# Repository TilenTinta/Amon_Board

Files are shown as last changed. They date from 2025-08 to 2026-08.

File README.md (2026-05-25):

# Amon Board — Flight Controller & Firmware

**Project Status:** In Progress

# Description:
Flight controller hardware and firmware used in the Amon Lander project. Two hardware lines are maintained:
- **Board v1 (ESP32 WROOM-32)** — never released (critical error).
- **Board v2 (STM32F405)** — the current, working design.
- **Board v3 (STM32H743VIT6)** — in development.
- **Board v4 (STM32xxx (Zephyr) + Raspberry Pi CM4)** — the next-gen design with a new MCU running Zephyr RTOS and a companion **Raspberry Pi Compute Module 4 (CM4)**.

> Part of the Amon Lander project:
>
> - **Amon Lander** — overall vehicle, frame, test/control SW, and data  
>   https://github.com/TilenTinta/Amon_Lander  
> - **Amon Link** — PC - drone communications (PCB + firmware)  
>   https://github.com/TilenTinta/Amon_Link  
> - **Amon Ground Control** — desktop GCS for telemetry & control  
>   https://github.com/TilenTinta/Amon_GroundControl_Software

---

## Table of Contents

- [Overview](#overview)
- [Hardware Versions](#hardware-versions)
  - [Board v2 — STM32F405](#board-v1--stm32f405)
  - [Board v3 — STM32H743](#board-v1--stm32h743)
  - [Board v4 — Zephyr + CM4](#board-v2--zephyr--cm4)
- [Version Matrix](#version-matrix)
- [Repository Structure](#repository-structure)
- [Getting Started](#getting-started)
  - [Build & Flash: Board v2 & v3](#build--flash-board-v1)
  - [Build & Flash: Board v4 (Zephyr)](#build--flash-board-v2-zephyr)
  - [First Boot: CM4 Companion](#first-boot-cm4-companion)
- [Calibration & Testing](#calibration--testing)
- [Roadmap](#roadmap)
- [Status & Disclaimer](#status--disclaimer)
- [License](#license)
- [Acknowledgments](#acknowledgments)

---

## Overview

This board is a custom flight controller for **Amon Lander**. The **v2** generation uses an **STM32F405RGT6 (LQFP-64)** and a hand-written firmware stack (drivers from scratch, for learning and control). Because of the flight algorithm planned to be used in this project, the decision was made to modify the current **v2** PCB with a new MCU. This is the **STM32H743VIT6 (LQFP-100)** and to fix some issues and add features that were missing or incorrect in the previous version. A **v3** generation is being designed around a **Zephyr-supported MCU** for real-time control, that will be paired with a **Raspberry Pi CM4** for high-level tasks (GCS link, logging, navigation stack, future CV/ML, etc.) in **v4**.

Everything was built from the ground up — **electronics, firmware, and software**. Most tools used are **free** and widely available to makers. Expect a learning-first approach over simplicity: some solutions could be easier, but the point is to **learn and explore**.

---

## Hardware Versions

### Board v1 — ESP32 WROOM-32

**Highlights**

- **MCU:** ESP32 WROOM-32 module
- **Power & Protection**
  - Dual vertical **XT60** inputs (PCB PWR and EDF voltage)
  - **Reverse-polarity diode**
  - Max input tested: **12 V**
  - Two **LDO regulators**: 3.3V (MCU/sensors) & 5V/5A (servos)
- **Sensors**
  - **MPU6050** (IMU)
  - **BME280** (temp/pressure/humidity)
  - TOF connector for **VL53L1X**
- **Navigation & Comms**
  - **GPS** connector (GY-NEO6MV2)
  - **single NRF24L01+ PA/LNA** (RX–TX) module
  - **ESP32 WiFi** can be used for communication
- **I/O**
  - **PWM:** 4× servos + 1× EDF
  - Expansion: **SPI** & **I²C** headers
  - **USB** with surge protection (over CH340C)
  - **4-pin JTAG** header
  - **RGB status LED**
  - **Buzzer**
- **Storage:** **microSD** slot
- **PCB:** 4-layer

**Firmware (v1)**
- **Status:** Never really worked (ESP32 was eliminated from the project)

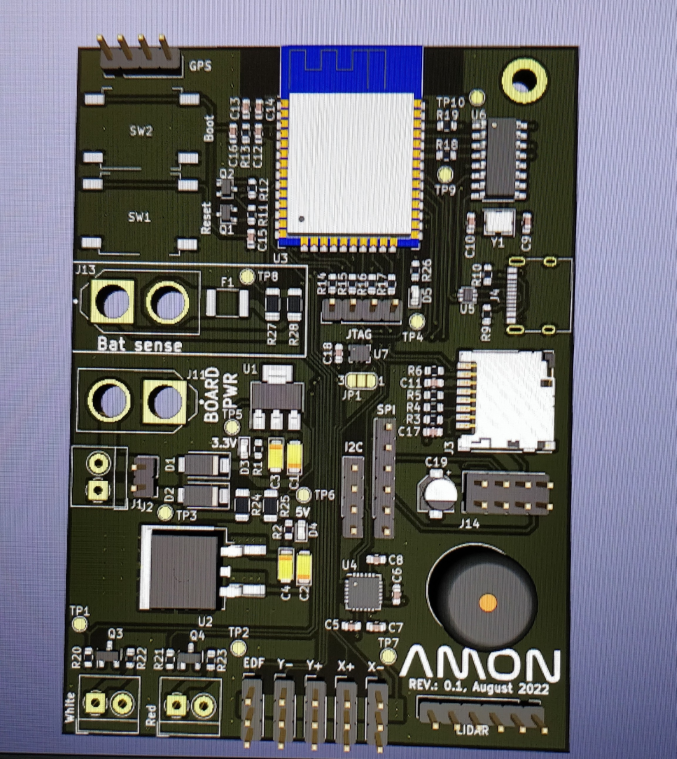
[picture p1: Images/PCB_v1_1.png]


### Board v2 — STM32F405

**Highlights**

- **MCU:** STM32F405RGT6 (LQFP-64) - Cortex M4, 168MHz, 196kB RAM, 1MB Flash
- **Power & Protection**
  - Dual vertical **XT60** inputs (PCB PWR and EDF voltage)
  - **Reverse-polarity diode**
  - Max input tested: **12 V**
  - Two **buck regulators**: 3.3 V (MCU/sensors) & 5 V (servos), ~5 A each
- **Switching/Startup:** Power-on by battery insertion or external switch on a terminal
- **Grounding:** Grounded mounting holes
- **Sensors**
  - **MPU6050** (IMU)
  - **BME280** (temp/pressure/humidity)
  - **HMC5883L** (compass) *added later
  - TOF connector for **VL53L1X**
- **Navigation & Comms**
  - **GPS** connector (GY-NEO6MV2; also reused for calibration)
  - **2× NRF24L01+ PA/LNA** (RX–TX)
- **I/O**
  - **PWM:** 4× servos + 1× EDF (configurable)
  - Expansion: **SPI** & **I²C** headers
  - **USB OTG** with surge protection
  - **10-pin JTAG** header
  - **RGB status LED**
- **Storage:** External flash (telemetry) + **microSD** slot
- **PCB:** 4-layer, working but slated for a future revision/refresh

**Firmware (v2)**

- **Approach:** Minimal dependencies; **drivers from scratch** (for learning)  
- **Status:** Runs and evolves; some drivers may still have rough edges  
- **Focus:** Bring-up, sensor fusion, basic control loops, telemetry logging and transmition...

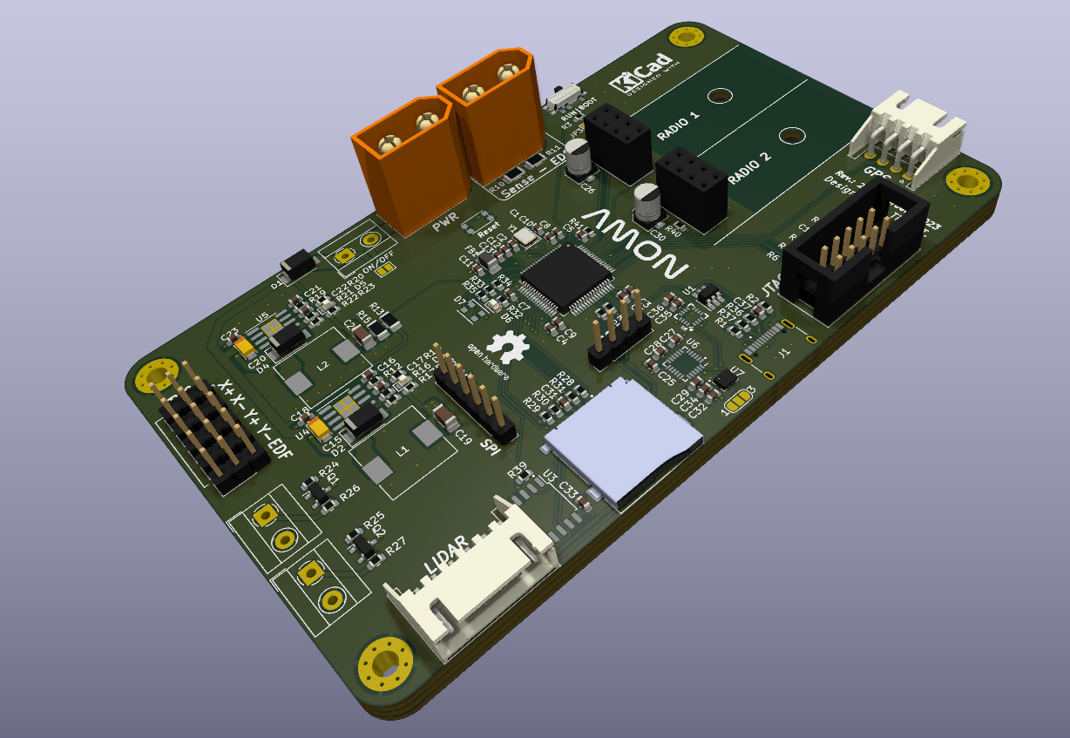
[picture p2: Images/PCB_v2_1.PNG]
PCBv2_1
> 

### Board v3 — STM32H743

**Highlights**

- **MCU:** STM32H743VIT66 (LQFP-100) - Cortex M7, 480MHz, 1MB RAM, 2MB Flash
- **Power & Protection**
  - Dual horizontal **XT60** inputs (PCB PWR and EDF voltage)
  - **Reverse-polarity diode**
  - Max input tested: **12 V**
  - Three **buck regulators**: 3.3 V (MCU/sensors) & 5 V (ESC and placeholder) & 7.2 V (servos), ~5 A each + more stable voltage
- **Switching/Startup:** Power-on sequence 3.3V -> 5V -> 7.2V (monitoring of regulators output voltages and enable/disable function)
- **Grounding:** Grounded mounting holes
- **Sensors**
  - **MPU6050** (IMU)
  - **BME280** (temp/pressure/humidity)
  - **HMC5883L** (compass)
  - Connector for TOF - **VL53L1X**
  - Connector for optical flow - **PMW3901**
- **Navigation & Comms**
  - Connector for GPS module -**GY-NEO6MV2**
  - **2× NRF24L01+ PA/LNA** (RX–TX) now on PCB - eliminated use of modules
  - **USB** over serial chip (CH340G) - eliminated use of USB OTG
- **I/O**
  - **PWM:** 4× servos + 1× EDF
  - Expansion: **SPI** & **I²C** headers
  - **10-pin JTAG** header (Olimex HAB-VCR-010-LF)
  - **RGB status LED**
  - **Single RED status LED**
  - Three connector low **LED modules** and additional AUX connector for future use
- **Storage:** External flash (telemetry) + **microSD** slot
- **PCB:** 4-layer

**Firmware (v3)**

- **Base:** Firmware is fully based on **Firmware v2**
- **Approach:** Minimal dependencies; **drivers from scratch** (for learning)  
- **Status:** Runs and evolves; some drivers may still have rough edges  
- **Focus:** sensor fusion, advance control algorithms, telemetry logging and transmition...

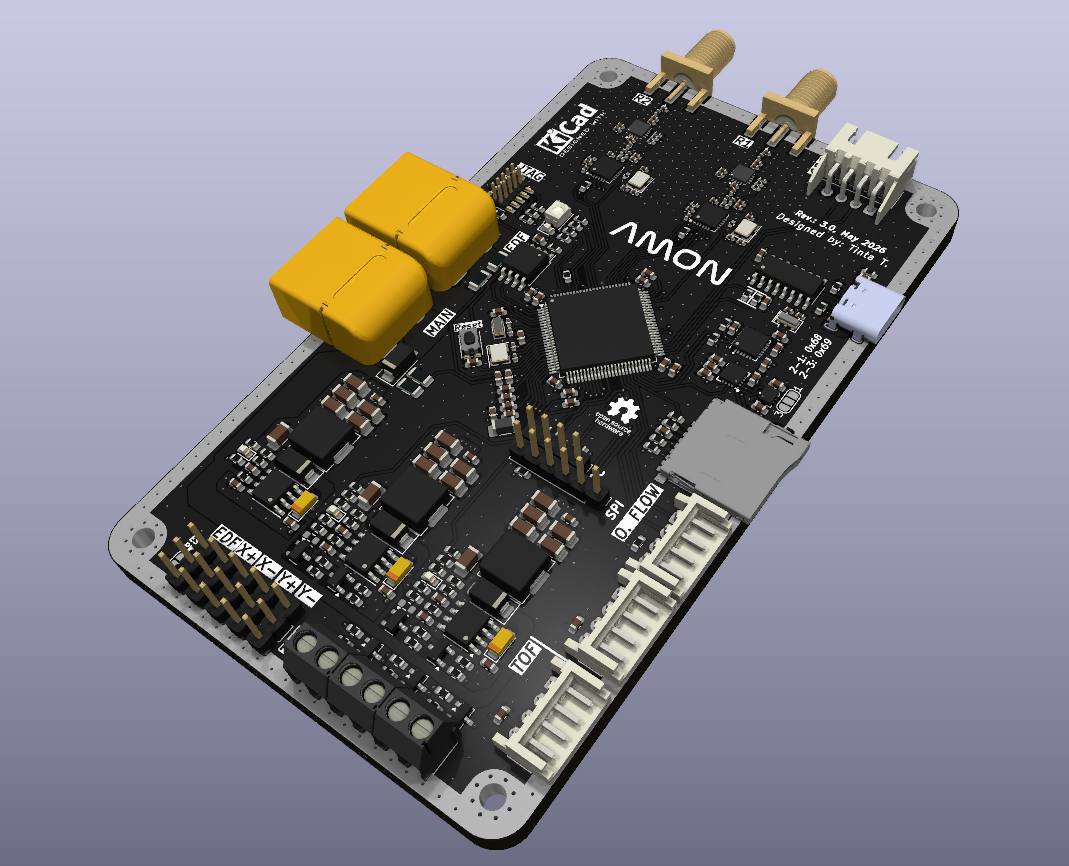
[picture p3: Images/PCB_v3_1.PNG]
PCBv3_1
> 

---

### Board v4 — Zephyr + CM4

**Architecture (planned / in development)**

- **Real-time MCU (Zephyr)**  
  - New MCU (TBD; Zephyr-supported) handles **Real-time**:
    - Sensor acquisition & fusion
    - Control loops (attitude/rate, TVC/actuators, EDF control)
    - Safety interlocks & failsafes
    - Deterministic logging (to QSPI flash / SD)
  - **Zephyr RTOS** app with:
    - Devicetree-based pin/peripheral config
    - Workqueues/threads for IMU, baro, magnetometer, TOF, PWM
    - Shell/CLI over UART/USB for diagnostics
    - Config storage (NVS) and firmware update hooks

- **Companion Computer — Raspberry Pi CM4**  
  - Runs services for:
    - Ground link, mission control, high-rate logging
    - Navigation stack expansion (mapping, state estimation helpers)
    - Future CV/ML applications (optional)
  - **Link to MCU:** UART (primary) + SPI/CAN (optional)  
  - **Services:** Telemetry bridge (to Amon Link), data recorder, configuration UI server
  - **OS:** Raspberry Pi OS Lite (or other lightweight Linux)

**Electrical**
- Robust power tree with multiple separated rails for servos/EDF vs logic
- MCU - CM4 isolation where needed (level shifting/ESD)
- On-board mass storage for logs (eMMC on CM4 + SD/QSPI on MCU)
- External debug: SWD/JTAG for MCU; USB-C or Ethernet for CM4

**Firmware (v4)**

- **Zephyr** application (modules: sensors, control, comms, storage)
- **IPC format:** CBOR/Protobuf frame over UART (CRC-guarded)
- **Bootloaders & Updates:** MCU bootloader (serial/DFU), CM4 apt-based or containerized deployment
- **Testing:** HIL hooks; replay logs for control tuning

---

## Version Matrix

## Version Matrix

| Capability | Board v1 — ESP32 | Board v2 — STM32F405 | Board v3 — STM32H743 | Board v4 — Zephyr + CM4 |
|---|---|---|---|---|
| MCU | ESP32 WROOM-32 | STM32F405RGT6 | STM32H743VIT6 | **TBD (Zephyr-supported)** |
| RTOS | None | None (bare-metal) | None (bare-metal) | **Zephyr RTOS** |
| Companion Computer | — | — | — | **Raspberry Pi CM4** |
| Sensors | MPU6050, BME280, VL53L1X | MPU6050, BME280, HMC5883L, VL53L1X | MPU6050, BME280, HMC5883L, VL53L1X | Same class; final selection TBD |
| Radio | 1× NRF24L01+ PA/LNA | 2× NRF24L01+ PA/LNA | 2× NRF24L01+ PA/LNA | TBD (NRF / other via MCU or CM4) |
| Navigation | GPS (GY-NEO6MV2) | GPS (GY-NEO6MV2) | GPS (GY-NEO6MV2) | GPS via MCU or CM4 module |
| Storage | microSD | Flash + microSD | Flash + microSD | CM4 eMMC + MCU flash/SD  |
| USB | USB (CH340C) | USB OTG | USB OTG + CH340G | USB (MCU + CM4) |
| Programming / Debug | 4-pin JTAG | 10-pin JTAG | 10-pin JTAG | SWD/JTAG (MCU) + SSH/USB/Ethernet (CM4) |
| PWM Outputs | 4× servos + 1× EDF | 4× servos + 1× EDF | 4× servos + 1× EDF | Same (handled by MCU) |
| Expansion | SPI, I²C | SPI, I²C | SPI, I²C | SPI, I²C, UART, CAN (planned) |
| Power | XT60, LDO (3.3V + 5V/5A) | XT60, buck (3.3V + 5V/5A + 7.2V) | XT60, improved buck (3.3V + 5V/5A) | Segregated rails, higher headroom (TBD) |
| PCB | 4-layer | 4-layer | 4-layer | TBD |
| Firmware Status | Not working | Working, evolving | In development | In development |
| Firmware Approach | — | Bare-metal, custom drivers | Based on v2, improved | Zephyr modules + Linux services |
| Firmware Updates | USB | JTAG/SWD/DFU | JTAG/SWD/DFU | MCU bootloader + CM4 (apt/container) |

---

## Getting Started

### Build & Flash: Board v1

1. **Clone**
   ```bash
   git clone https://github.com/<your-org-or-user>/Amon_Board.git
   cd Amon_Board/firmware/Amon_board_firmware-MCU
   ```
2. **Toolchain**
   - Install `arm-none-eabi-gcc` and your preferred STM32 flashing tool.
3. **Configure - can be automatic**
   - Target: **STM32F405RG**; enable FPU; set clock tree; verify linker script.
4. **Build**
   ```bash
   make
   ```
   or use your IDE’s Build action.
5. **Flash**
   - Via **JTAG/SWD** (10-pin header) using your probe (ST-Link, J-Link, etc.).
6. **Verify**
   - Rails at 5 V/3.3 V, sensor presence on I²C/SPI, status RGB LED patterns.

---

### Build & Flash: Board v2 (Zephyr)
Instructions bellow are only "place holder". Detailed instructions will be provided once the development will be started. For flashing and debugging will be used Segger Ozone software.

1. **Prerequisites**
   - Install **Zephyr SDK**, Python, CMake, Ninja.
   - Install **west**: `pip install west`
2. **Get Sources**
   ```bash
   cd Amon_Board/firmware/v2-zephyr
   west init -l .
   west update
   ```
3. **Board Definition**
   - Use the custom board under `boards/amon_v2/` (edit SoC, pins, clocks, and flash layout as needed).
4. **Build**
   ```bash
   west build -b amon_v2 app
   ```
5. **Flash**
   ```bash
   west flash
   ```
6. **Console**
   ```bash
   west espressif monitor   # or 'west zephyr monitor' / minicom, depending on target
   ```
   *(Choose the appropriate monitor command for your MCU/OS.)*

---

### First Boot: CM4 Companion

1. **Flash OS**
   - Install **Raspberry Pi OS Lite** to CM4’s eMMC or carrier-board storage.
2. **Enable Interfaces**
   - `sudo raspi-config` → enable UART, I2C, SPI as needed.
3. **Install Services**
   ```bash
   sudo apt update
   sudo apt install python3-pip git
   git clone https://github.com/<your-org-or-user>/amon-cm4-services.git
   cd amon-cm4-services && ./install.sh
   ```
   - Starts a telemetry bridge (serial↔TCP/gRPC), data logger, and config UI.
4. **Connect to MCU**
   - Wire UART (and optionally SPI/CAN) between CM4 and MCU.
   - Confirm link with a ping/handshake command.
5. **Network Access**
   - SSH into CM4; forward telemetry to **Amon Ground Control** over Wi-Fi/Ethernet.

---

## Calibration & Testing

- **GPS/Calibration Port:** The v2 GPS connector doubles as a calibration interface during bring-up. PCB v3 do this over USB.  
- **Telemetry:** Log to external flash/microSD (v2 & v3) or CM4 eMMC + MCU storage (v4).  
- **LED Status:** On-board RGB LED signals power, init, errors, and link status.  
- **HIL/Replay (v2):** Reproduce flights by streaming recorded sensor frames back into the MCU (for controller tuning).

---

## Roadmap

- **v1**
   - Failed design
- **v2**
  - Incremental driver fixes and documentation cleanup
  - Manufacturing files refresh (Gerbers/BOM/PNP)
- **v3**
   - Modified v2 design with new MCU, connectors, sensors
   - Modified v2 firmware for new MCU (much higher clock: 168 MHz -> 480MHz)
   - Development of flight algorithm and controller + first flights 
- **v4**
  - Finalize MCU choice and Zephyr board port
  - Define IPC schema (CBOR/Proto) & reliability (CRC/seq/ACK)
  - CM4 services (logger, bridge, config UI)
  - Development of new flight algorithm and controllers + flights 

---

## Status & Disclaimer

- **Works, but in progress:** v2 firmware runs; development is active and some drivers may still have rough edges.  
- **New hardware incoming:** v2/v3/v4 will introduce a Zephyr-based MCU and CM4 companion; designs are evolving.

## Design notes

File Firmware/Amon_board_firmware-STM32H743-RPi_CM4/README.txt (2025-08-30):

1) MCU

2) RPi
	- optical flow
	- shared memory
	- multi process (UART, CAM + QOI?, RFTX, RFRX, GPS, Optical flow)

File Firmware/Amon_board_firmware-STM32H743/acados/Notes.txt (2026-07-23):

Run auto copy and modify code from powershell with:
powershell.exe -ExecutionPolicy Bypass -File ".\update_acados_files.ps1"

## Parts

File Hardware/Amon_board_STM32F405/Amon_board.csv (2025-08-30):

Id | Designator | Package | Quantity | Designation
1 | JP2 | SolderJumper-3_P2.0mm_Open_TrianglePad1.0x1.5mm_NumberLabels | 1 | I2C address
2 | H2,H1,H4,H3 | MountingHole_3.2mm_M3_Pad_Via | 4 | MountingHole_Pad
3 | R7,R9,R8,R6 | R_0603_1608Metric | 4 | 100
4 | C14,C21,C16,C13,C10,C5,C34,C9,C7,C32,C8 | C_0603_1608Metric | 11 | 100nF
5 | J4,J5 | AMASS_XT60-M | 2 | XT60-F
6 | J14 | PinHeader_1x04_P2.54mm_Vertical | 1 | Conn_01x04_Male
7 | R25,R24,R26,R27 | R_0603_1608Metric | 4 | 1k
8 | R13,R10 | R_1206_3216Metric | 2 | 100k
9 | R34,R33,R32,R35 | R_0603_1608Metric | 4 | 330
10 | R12,R19 | R_0603_1608Metric | 2 | 100k
11 | L1,L2 | L_10.4x10.4_H4.8 | 2 | 10uH 4A
12 | R22 | R_0603_1608Metric | 1 | 44k
13 | R17 | R_0603_1608Metric | 1 | 26k1
14 | C25,C27,C28 | C_0603_1608Metric | 3 | 0.1uF
15 | D4,D2,D1 | D_SMA | 3 | B120-E3
16 | J7 | TerminalBlock_MetzConnect_Type055_RT01502HDWU_1x02_P5.00mm_Horizontal | 1 | Red leds
17 | U3 | SOIC-8_5.23x5.23mm_P1.27mm | 1 | W25Q128JVS
18 | R1,R2 | R_0603_1608Metric | 2 | 5k1
19 | J9,J6 | PinSocket_2x04_P2.54mm_Vertical | 2 | Conn_02x04_Odd_Even
20 | U7 | Bosch_LGA-8_2x2.5mm_P0.65mm_ClockwisePinNumbering | 1 | BME280
21 | J3 | TerminalBlock_MetzConnect_Type055_RT01502HDWU_1x02_P5.00mm_Horizontal | 1 | Switch_port
22 | R3,R29,R30,R21,R28,R31,R16 | R_0603_1608Metric | 7 | 10k
23 | M4 | PinHeader_1x03_P2.54mm_Vertical | 1 | Servo_Y-
24 | C15,C20 | CP_EIA-3216-10_Kemet-I | 2 | 10uF
25 | J2 | IDC-Header_2x05_P2.54mm_Vertical | 1 | Conn_2x5 pin
26 | R18,R23 | R_0603_1608Metric | 2 | 1k5
27 | J8 | TerminalBlock_MetzConnect_Type055_RT01502HDWU_1x02_P5.00mm_Horizontal | 1 | White leds
28 | J11 | PinHeader_1x03_P2.54mm_Vertical | 1 | Conn_01x03_Male
29 | J1 | USB_C_Receptacle_XKB_U262-16XN-4BVC11 | 1 | USB2.0_C_Rev
30 | C12,C33,C11 | C_0603_1608Metric | 3 | 1uF
31 | JP3 | SolderJumper-2_P1.3mm_Open_TrianglePad1.0x1.5mm | 1 | SolderJumper_2_Open
32 | C2,C1 | C_0603_1608Metric | 2 | 14pF
33 | U1 | SOT-23-6_Handsoldering | 1 | USBLC6-2P6
34 | R4,R5 | R_0603_1608Metric | 2 | 4k7
35 | J12 | JST_XH_S6B-XH-A-1_1x06_P2.50mm_Horizontal | 1 | Conn_01x06_Male
36 | M2 | PinHeader_1x03_P2.54mm_Vertical | 1 | Servo_X-
37 | C24,C19 | C_0603_1608Metric | 2 | 22uF
38 | J10 | AMPHENOL_GTFP08131Y2HR | 1 | GTFP08131Y2HR
39 | SW2 | SW_Push_1P1T_NO_CK_KMR2 | 1 | SW_SPST
40 | C3 | C_0603_1608Metric | 1 | 4.7uF
41 | U5,U4 | SOIC-8-1EP_3.9x4.9mm_P1.27mm_EP2.62x3.51mm | 2 | MP2303ADN
42 | FB1 | L_1206_3216Metric_Pad1.22x1.90mm_HandSolder | 1 | 100R 100MHz
43 | C31 | C_0603_1608Metric | 1 | 10uF
44 | C22,C17 | C_0603_1608Metric | 2 | 3.9nF
45 | R20,R14 | R_0603_1608Metric | 2 | 6k8
46 | SW1 | SW_SPDT_PCM12 | 1 | SW_DPDT
47 | J13 | JST_XH_S4B-XH-A_1x04_P2.50mm_Horizontal | 1 | Conn_01x04_Male
48 | Y1 | Crystal_SMD_3225-4Pin_3.2x2.5mm | 1 | 25MHz
49 | C30,C26 | CP_Elec_4x5.4 | 2 | 10uF
50 | D3,D5 | LED_0603_1608Metric | 2 | Red
51 | C18,C23 | C_0603_1608Metric | 2 | 10nF
52 | R15,R11 | R_1206_3216Metric | 2 | 10k
53 | D7 | LED_Cree-PLCC4_3.2x2.8mm_CCW | 1 | LED_RGBA
54 | Q1,Q2 | SOT-23 | 2 | BC817
55 | C4,C6 | C_0603_1608Metric | 2 | 2.2uF
56 | U2 | LQFP-64_10x10mm_P0.5mm | 1 | STM32F405RGT6-LQFP64
57 | U6 | InvenSense_QFN-24_4x4mm_P0.5mm | 1 | MPU-6050
58 | M1 | PinHeader_1x03_P2.54mm_Vertical | 1 | Servo_X+
59 | JP1 | SolderJumper-2_P1.3mm_Open_Pad1.0x1.5mm | 1 | SolderJumper_2_Open
60 | M3 | PinHeader_1x03_P2.54mm_Vertical | 1 | Servo_Y+
61 | J15 | PinHeader_1x06_P2.54mm_Vertical | 1 | Conn_01x06_Male
62 | C29 | C_0603_1608Metric | 1 | 2.2nF
63 | D6 | LED_0603_1608Metric | 1 | RED
64 | H6,H5 | MountingHole_3.2mm_M3 | 2 | MountingHole

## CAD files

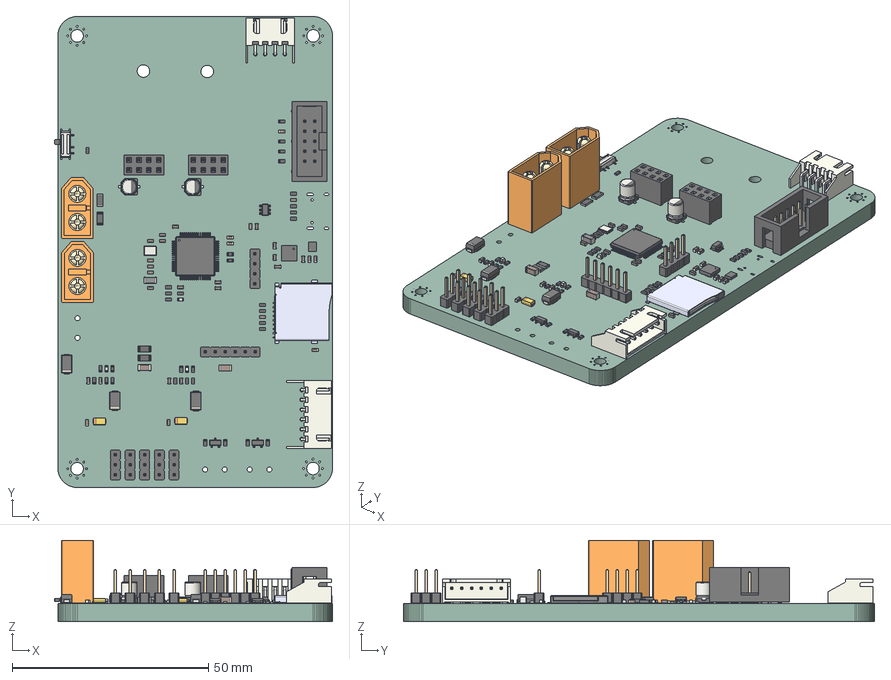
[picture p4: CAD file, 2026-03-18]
Hardware/Amon_board_STM32F405/Amon_board.step
70.9 x 120.0 x 20.7 mm
PCB

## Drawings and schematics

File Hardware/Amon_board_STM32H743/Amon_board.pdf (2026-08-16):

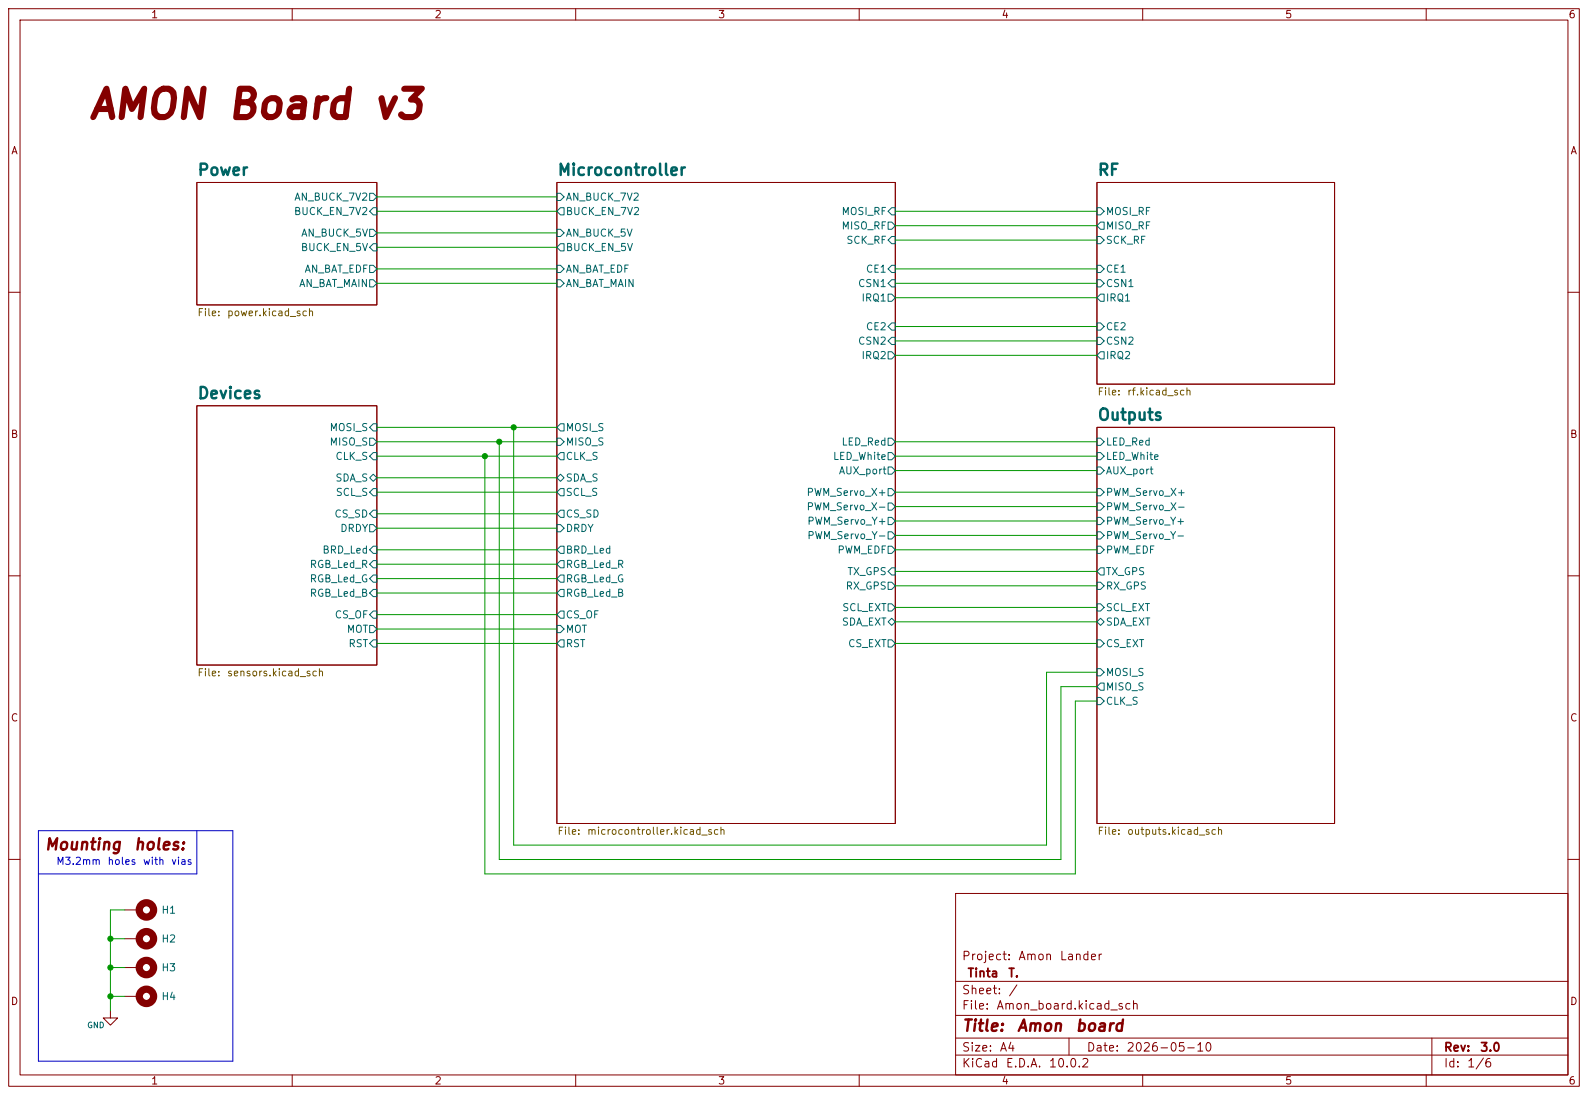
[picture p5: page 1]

M3.2mm holes with vias Mounting holes:

Size: A4 | Rev: 3.0
KiCad E.D.A. 10.0.2 | Id: 1/6

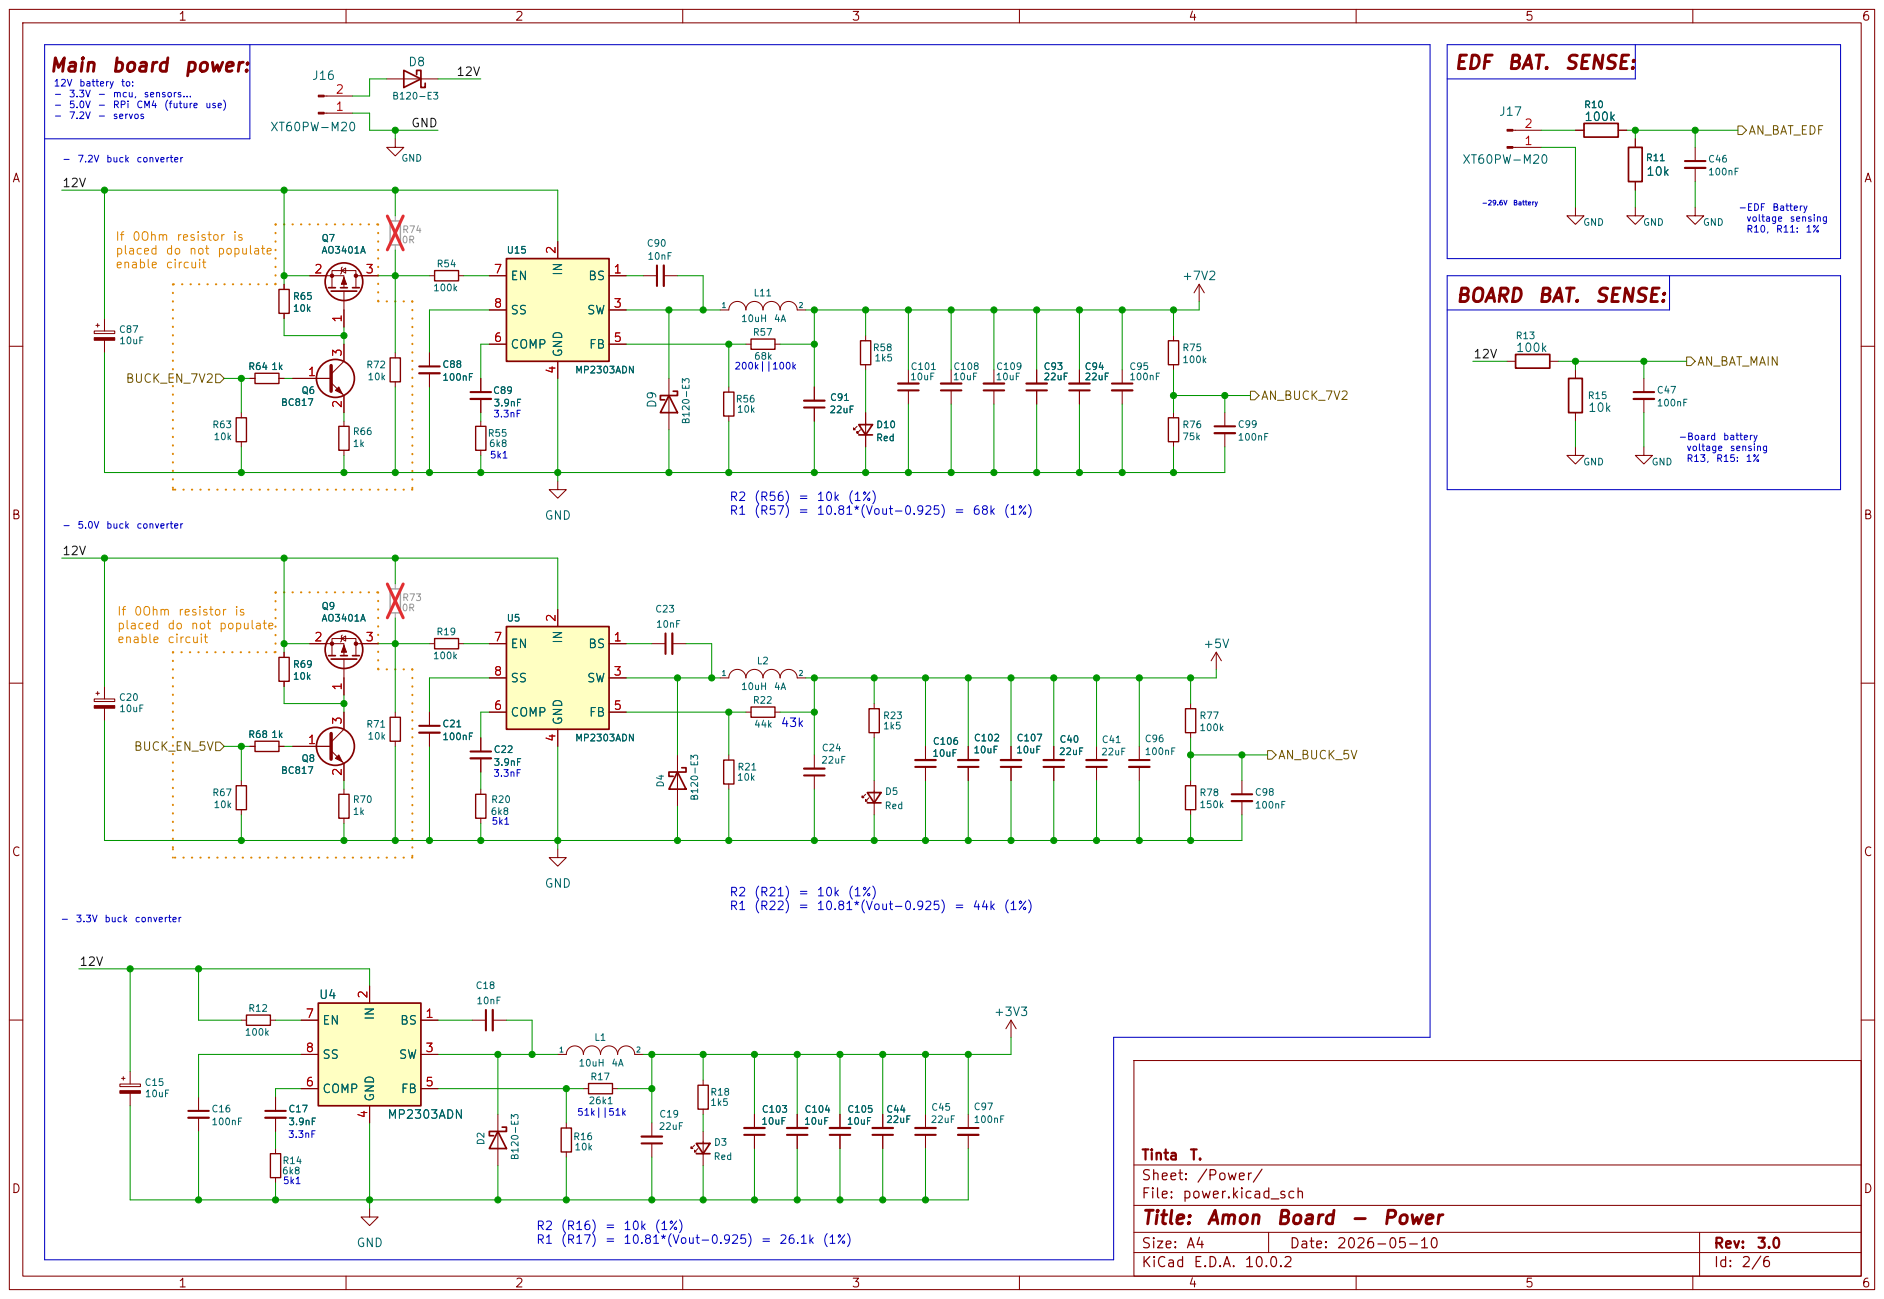
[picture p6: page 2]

Sheet: /Power/
File: power.kicad_sch
Title: Amon Board - Power

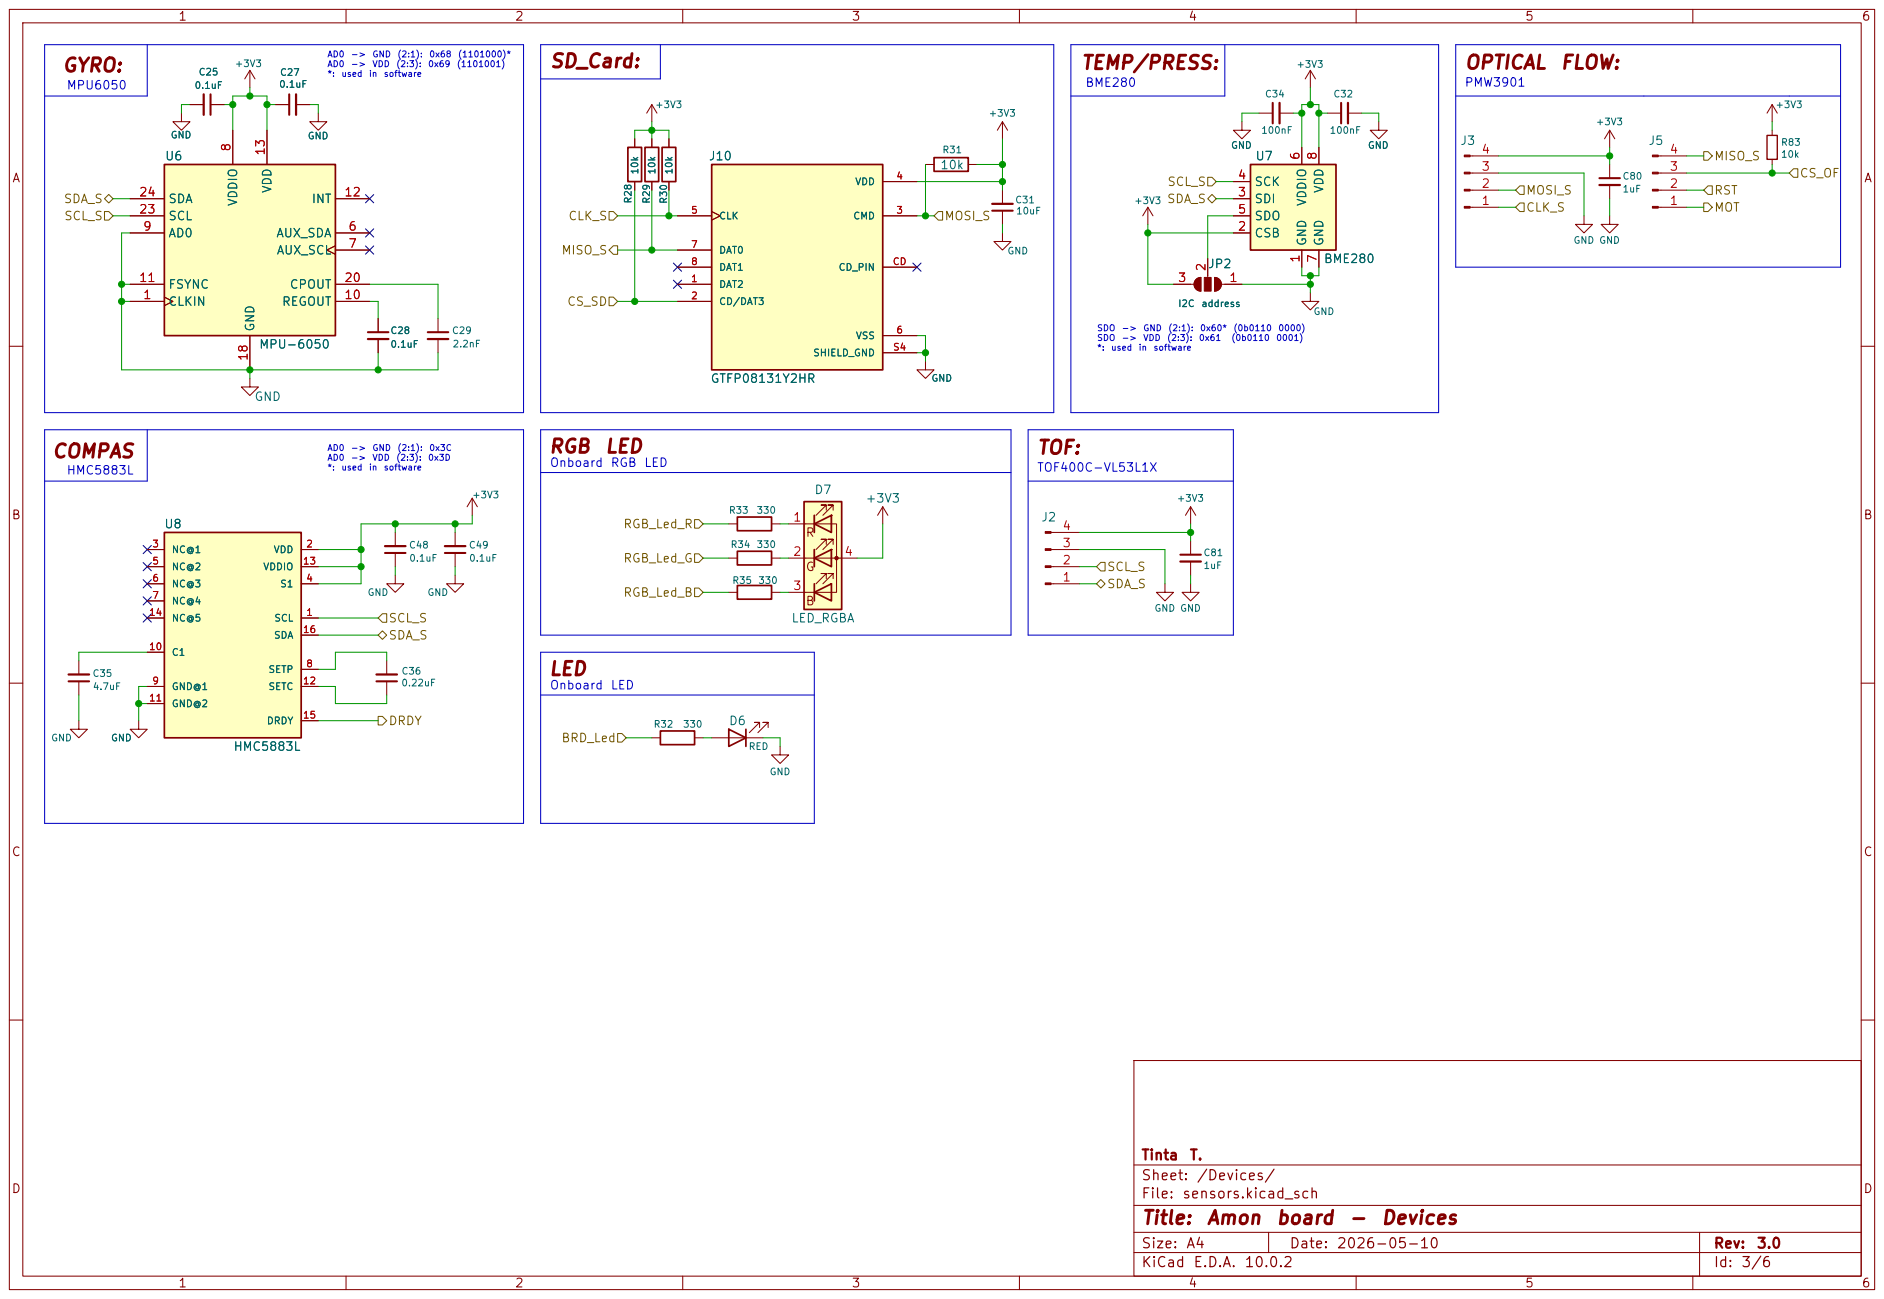
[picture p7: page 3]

AD0 -> GND (2:1): 0x68 (1101000)* AD0 -> VDD (2:3): 0x69 (1101001) *: used in software COMPAS

Tinta T.
Sheet: /Devices/
File: sensors.kicad_sch
Title: Amon board - Devices

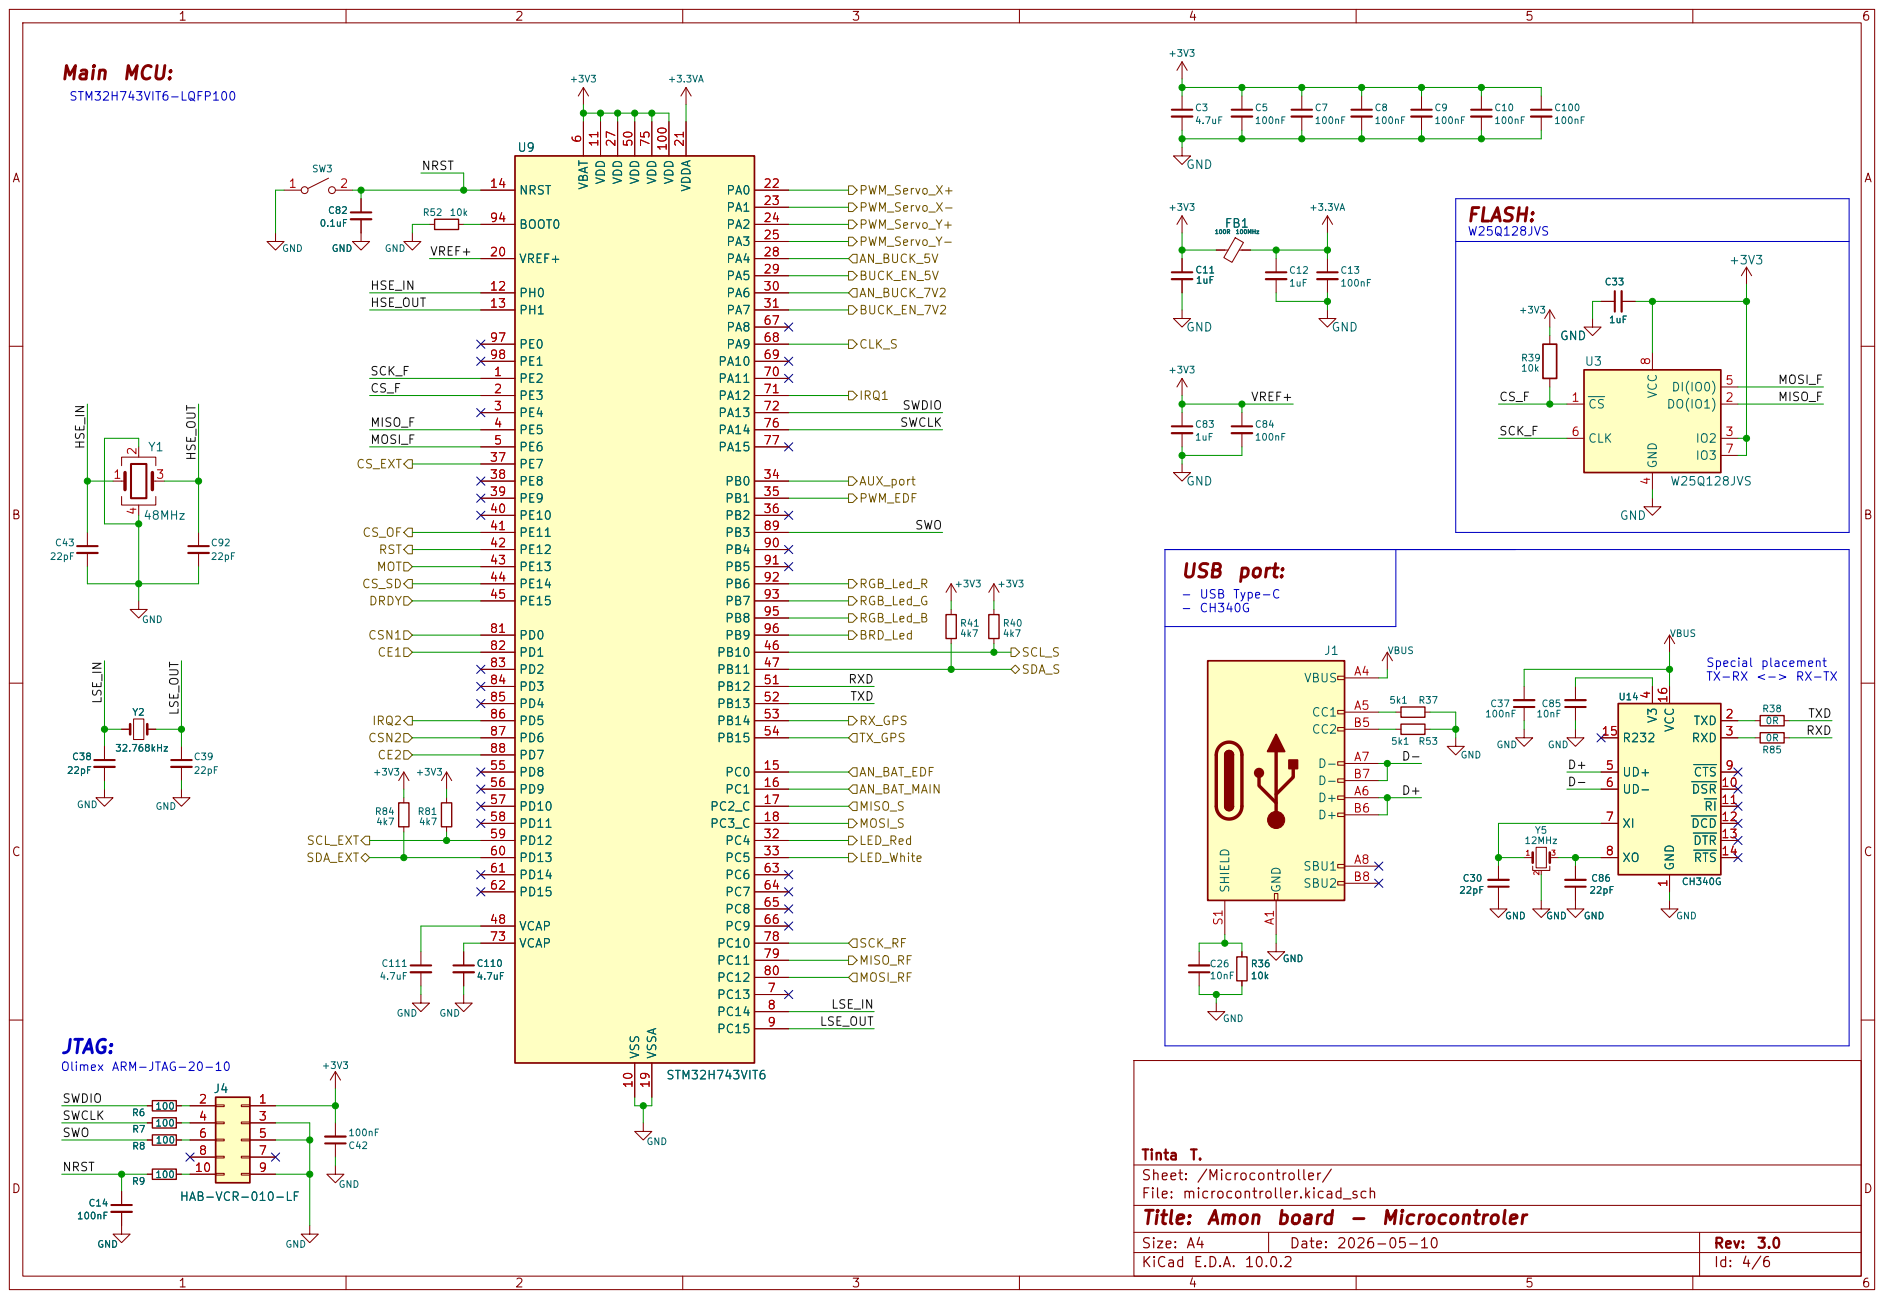
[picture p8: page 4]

Tinta T.
Sheet: /Microcontroller/
File: microcontroller.kicad_sch
Title: Amon board - Microcontroler

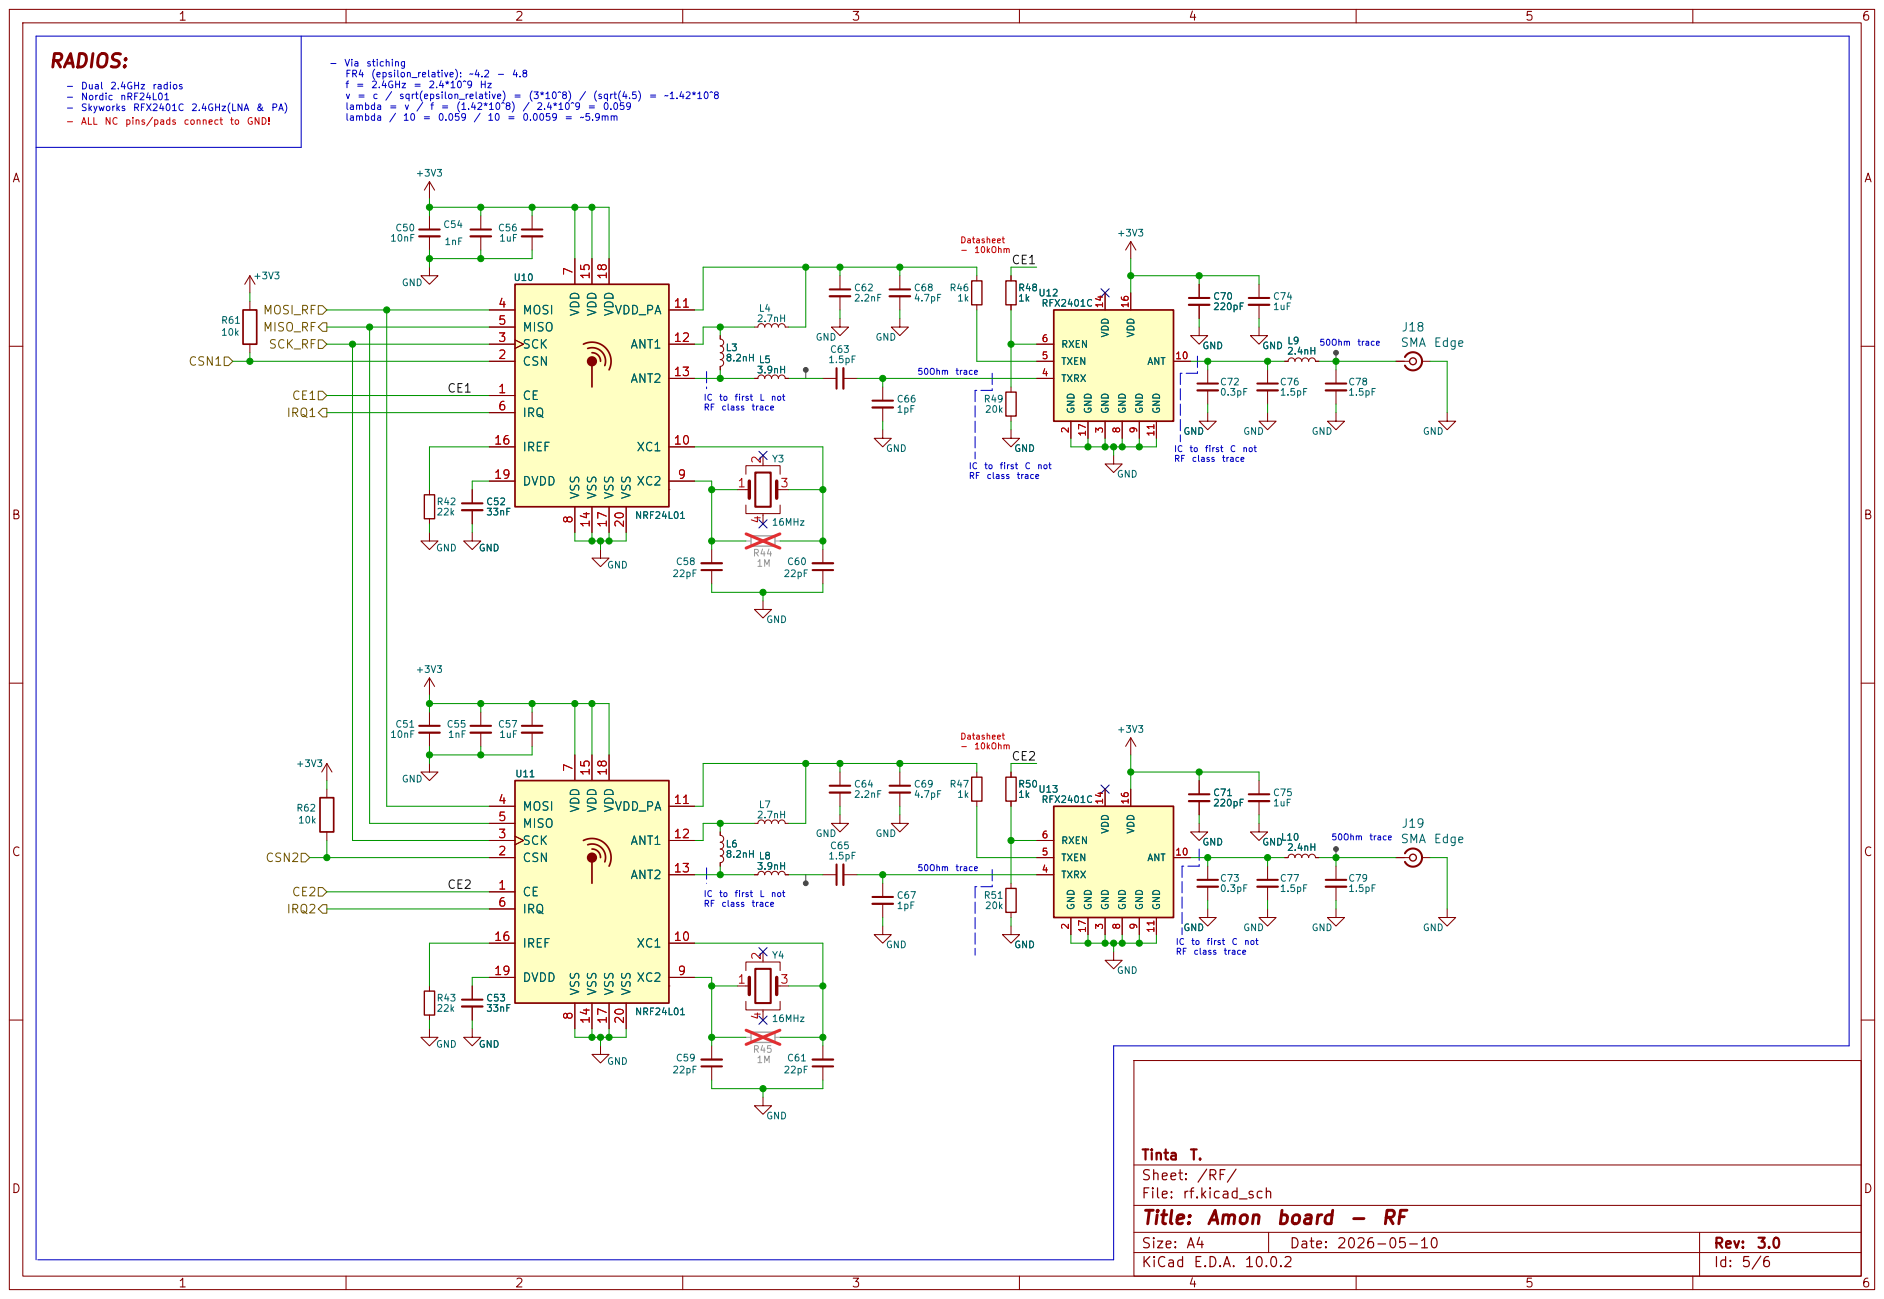
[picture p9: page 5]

IC to first C not RF class trace Datasheet - 10kOhm RADIOS: - Dual 2.4GHz radios - Nordic nRF24L01 - Skyworks RFX2401C 2.4GHz(LNA & PA)

- ALL NC pins/pads connect to GND!

IC to first L not RF class trace

IC to first C not RF class trace

Sheet: /RF/
File: rf.kicad_sch
Title: Amon board - RF

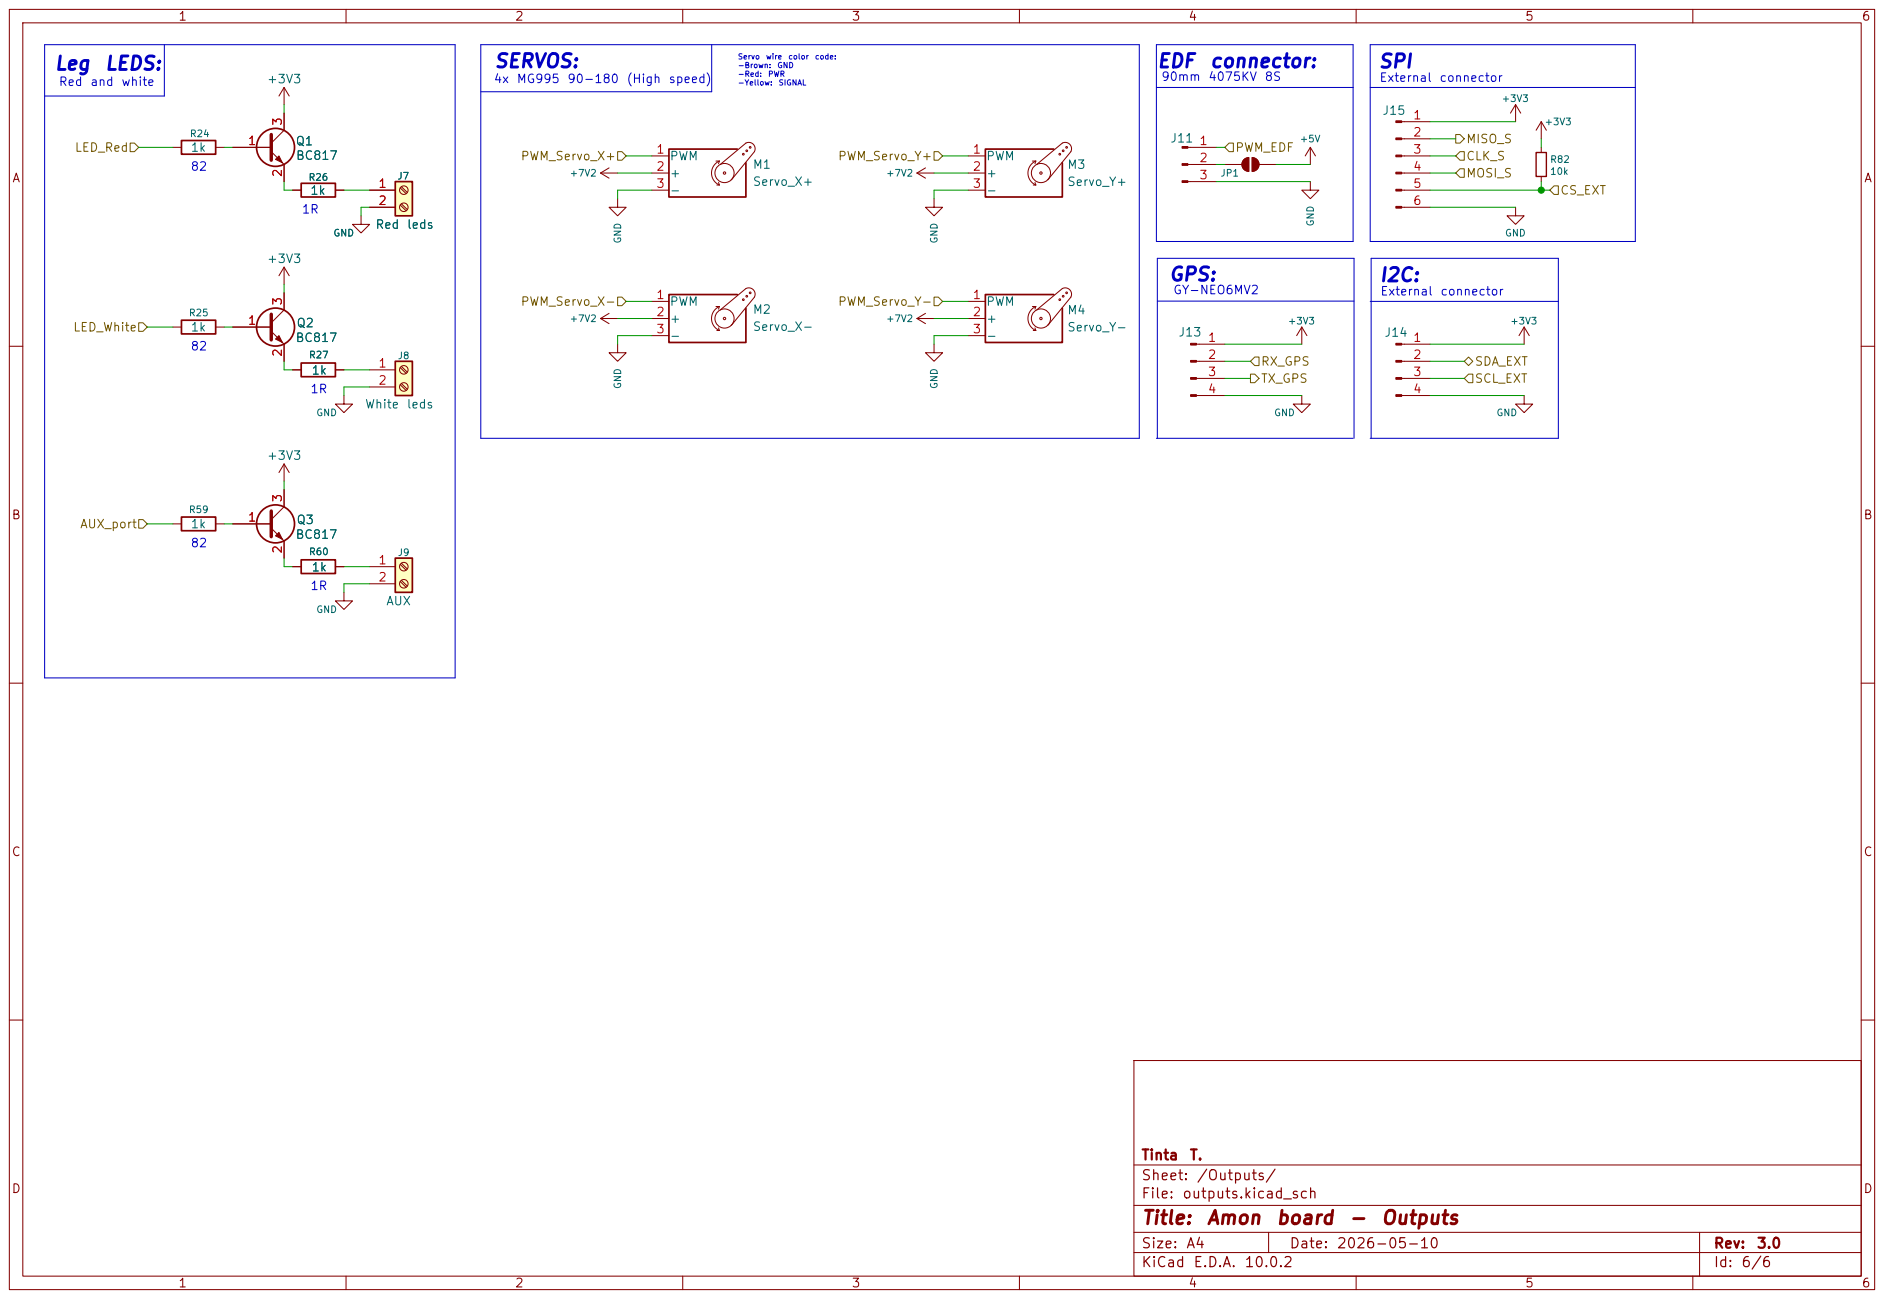
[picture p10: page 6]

Tinta T.
Sheet: /Outputs/
File: outputs.kicad_sch
Title: Amon board - Outputs

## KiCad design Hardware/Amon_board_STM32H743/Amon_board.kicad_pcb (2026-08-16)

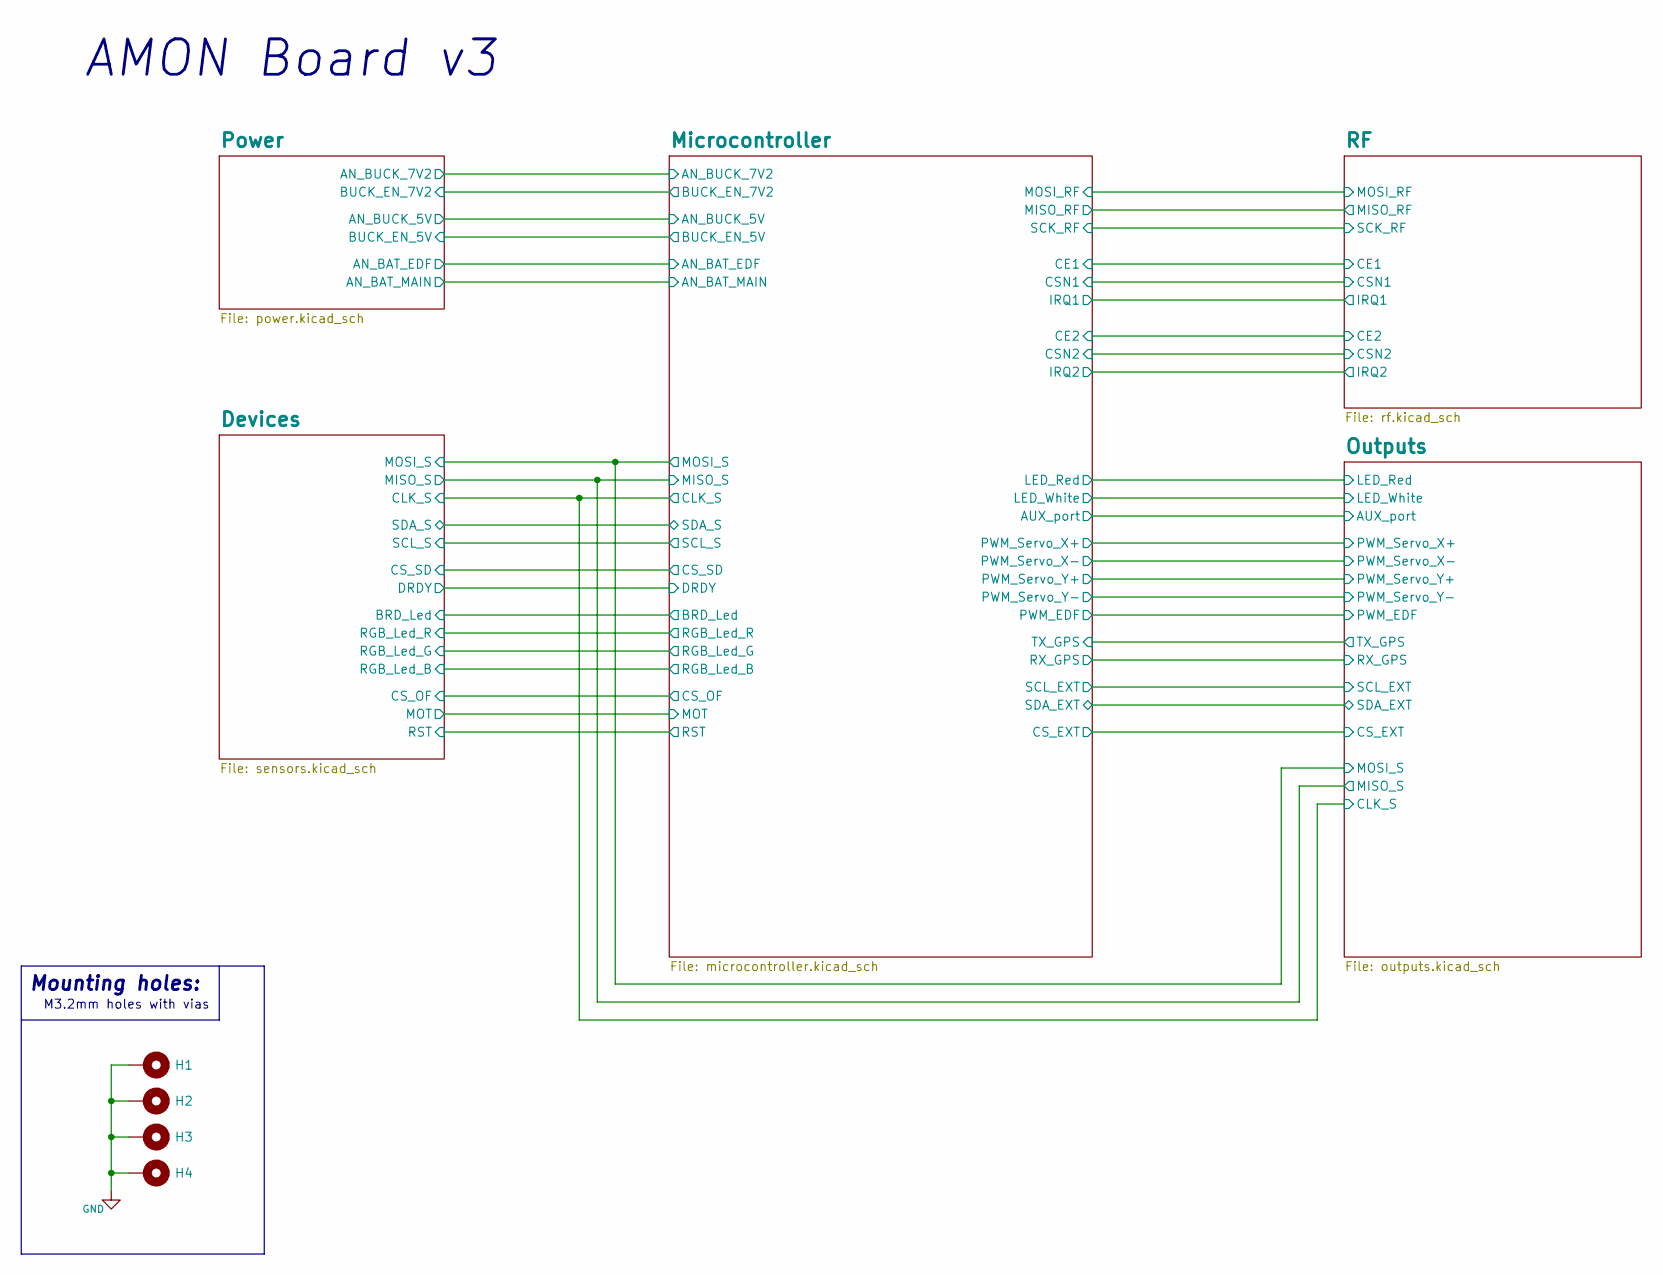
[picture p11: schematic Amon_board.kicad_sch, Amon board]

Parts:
H1, H2, H3, H4: MountingHole_Pad; MountingHole_3.2mm_M3_Pad_Via

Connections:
GND: H1.1 (1_1), H2.1 (1_1), H3.1 (1_1), H4.1 (1_1); also elsewhere on the board

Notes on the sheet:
M3.2mm holes with vias
Mounting holes:
AMON Board v3

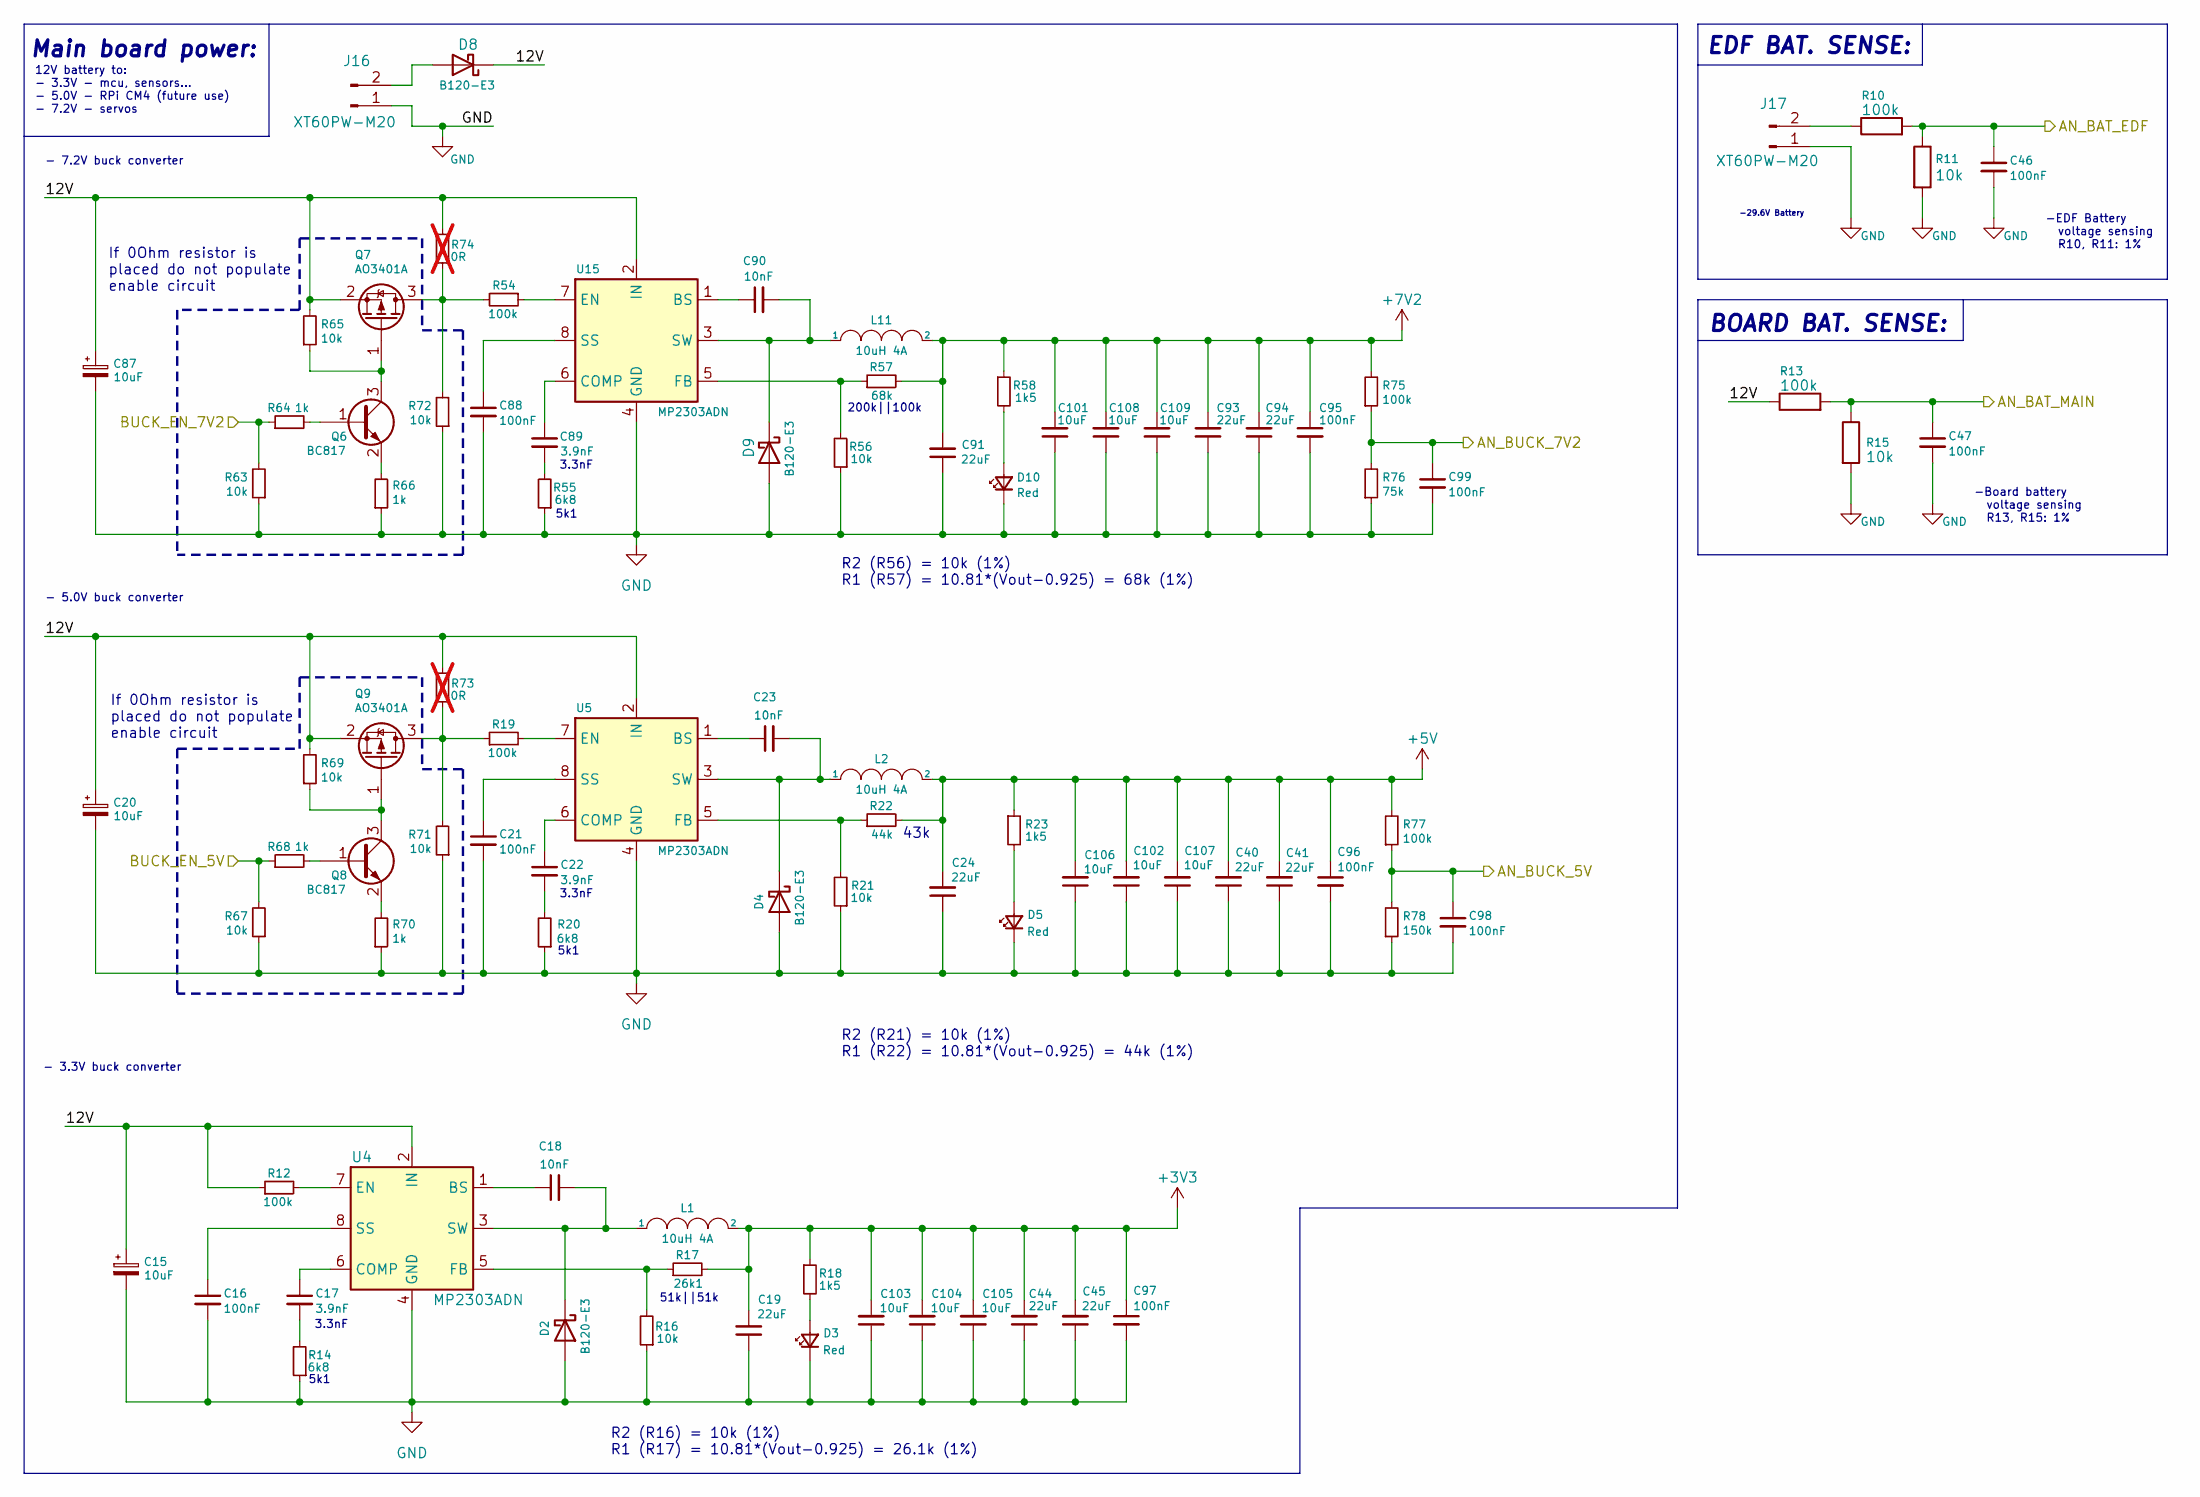
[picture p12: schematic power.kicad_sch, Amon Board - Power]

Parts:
C15, C20, C87: 10uF; CP_EIA-3216-10_Kemet-I
C16, C21, C46, C47, C88, C95, C96, C97, C98, C99: 100nF; C_0603_1608Metric
C17, C22, C89: 3.9nF; C_0603_1608Metric
C18, C23, C90: 10nF; C_0603_1608Metric
C19, C24, C40, C41, C44, C45, C91, C93, C94: 22uF; C_1206_3216Metric
C101, C102, C103, C104, C105, C106, C107, C108, C109: 10uF; C_1206_3216Metric
D2, D4, D8, D9: B120-E3; D_SMA
D3, D5, D10: Red; LED_0603_1608Metric
J16, J17: XT60PW-M20; AMASS_XT60PW-M_1x02_P7.20mm_Horizontal
L1, L2, L11: 10uH 4A; L_APV_APH0630
Q6, Q8: BC817; SOT-23
Q7, Q9: AO3401A; SOT-23
R10, R13: 100k; R_1206_3216Metric
R11, R15: 10k; R_1206_3216Metric
R12, R19, R54, R75, R77: 100k; R_0603_1608Metric
R14, R20, R55: 6k8; R_0603_1608Metric
R16, R21, R56, R63, R65, R67, R69, R71, R72: 10k; R_0603_1608Metric
R17: 26k1; R_0603_1608Metric
R18, R23, R58: 1k5; R_0603_1608Metric
R22: 44k; R_0603_1608Metric
R57: 68k; R_0603_1608Metric
R64, R66, R68, R70: 1k; R_0603_1608Metric
R73, R74: 0R; R_0603_1608Metric; not fitted
R76: 75k; R_0603_1608Metric
R78: 150k; R_0603_1608Metric
U4, U5, U15: MP2303ADN; SOIC-8-1EP_3.9x4.9mm_P1.27mm_EP2.62x3.51mm

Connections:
+3V3: C19.2, C44.2, C45.2, C97.1, C103.2, C104.2, C105.2, L1.2, R17.2, R18.1; also elsewhere on the board
+5V: C24.2, C40.2, C41.2, C96.1, C102.2, C106.2, C107.2, L2.2, R22.2, R23.1, R77.2; also elsewhere on the board
+7V2: C91.2, C93.2, C94.2, C95.1, C101.2, C108.2, C109.2, L11.2, R57.2, R58.1, R75.2; also elsewhere on the board
/Microcontroller/AN_BAT_EDF: C46.1, R10.2, R11.1; also elsewhere on the board
/Microcontroller/AN_BAT_MAIN: C47.1, R13.2, R15.1; also elsewhere on the board
/Microcontroller/AN_BUCK_5V: C98.1, R77.1, R78.2; also elsewhere on the board
/Microcontroller/AN_BUCK_7V2: C99.1, R75.1, R76.2; also elsewhere on the board
/Microcontroller/BUCK_EN_5V: R67.2, R68.1; also elsewhere on the board
/Microcontroller/BUCK_EN_7V2: R63.2, R64.1; also elsewhere on the board
/Power/12V: C15.1, C20.1, C87.1, D8.1 (K), Q7.2 (S), Q9.2 (S), R12.1, R13.1, R65.2, R69.2, R73.2, R74.2, U4.2 (IN), U5.2 (IN), U15.2 (IN)
GND: C15.2, C16.2, C19.1, C20.2, C21.2, C24.1, C40.1, C41.1, C44.1, C45.1, C46.2, C47.2, C87.2, C88.2, C91.1, C93.1, C94.1, C95.2, C96.2, C97.2, C98.2, C99.2, C101.1, C102.1, C103.1, C104.1, C105.1, C106.1, C107.1, C108.1, C109.1, D2.2 (A), D3.1 (K), D4.2 (A), D5.1 (K), D9.2 (A), D10.1 (K), J16.1, J17.1, R11.2, R14.1, R15.2, R16.1, R20.1, R21.1, R55.1, R56.1, R63.1, R66.1, R67.1, R70.1, R71.1, R72.1, R76.1, R78.1, U4.4 (GND), U5.4 (GND), U15.4 (GND); also elsewhere on the board
unnamed: C17.2, R14.2
unnamed: C22.2, R20.2
unnamed: C89.2, R55.2
unnamed: C18.2, D2.1 (K), L1.1, U4.3 (SW)
unnamed: D3.2 (A), R18.2
unnamed: C23.2, D4.1 (K), L2.1, U5.3 (SW)
unnamed: D5.2 (A), R23.2
unnamed: D8.2 (A), J16.2
unnamed: C90.2, D9.1 (K), L11.1, U15.3 (SW)
unnamed: D10.2 (A), R58.2
unnamed: J17.2, R10.1
unnamed: Q6.1 (B), R64.2
unnamed: Q6.3 (C), Q7.1 (G), R65.1
unnamed: Q6.2 (E), R66.2
unnamed: Q7.3 (D), R54.2, R72.2, R74.1
unnamed: Q8.1 (B), R68.2
unnamed: Q8.3 (C), Q9.1 (G), R69.1
unnamed: Q8.2 (E), R70.2
unnamed: Q9.3 (D), R19.1, R71.2, R73.1
unnamed: C18.1, U4.1 (BS)
unnamed: C17.1, U4.6 (COMP)
unnamed: R12.2, U4.7 (EN)
unnamed: R16.2, R17.1, U4.5 (FB)
unnamed: C16.1, U4.8 (SS)
unnamed: C23.1, U5.1 (BS)
unnamed: C22.1, U5.6 (COMP)
unnamed: R19.2, U5.7 (EN)
unnamed: R21.2, R22.1, U5.5 (FB)
unnamed: C21.1, U5.8 (SS)
unnamed: C90.1, U15.1 (BS)
unnamed: C89.1, U15.6 (COMP)
unnamed: R54.1, U15.7 (EN)
unnamed: R56.2, R57.1, U15.5 (FB)
unnamed: C88.1, U15.8 (SS)

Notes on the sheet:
-Board battery voltage sensing R13, R15: 1%
51k||51k
200k||100k
- 7.2V buck converter
R2 (R56) = 10k (1%) R1 (R57) = 10.81*(Vout-0.925) = 68k (1%)
- 5.0V buck converter
BOARD BAT. SENSE:
5k1
-29.6V Battery
-EDF Battery voltage sensing R10, R11: 1%
If 0Ohm resistor is placed do not populate enable circuit
12V battery to: - 3.3V - mcu, sensors... - 5.0V - RPi CM4 (future use) - 7.2V - servos
- 3.3V buck converter
3.3nF
EDF BAT. SENSE:
R2 (R21) = 10k (1%) R1 (R22) = 10.81*(Vout-0.925) = 44k (1%)
43k
Main board power:
R2 (R16) = 10k (1%) R1 (R17) = 10.81*(Vout-0.925) = 26.1k (1%)

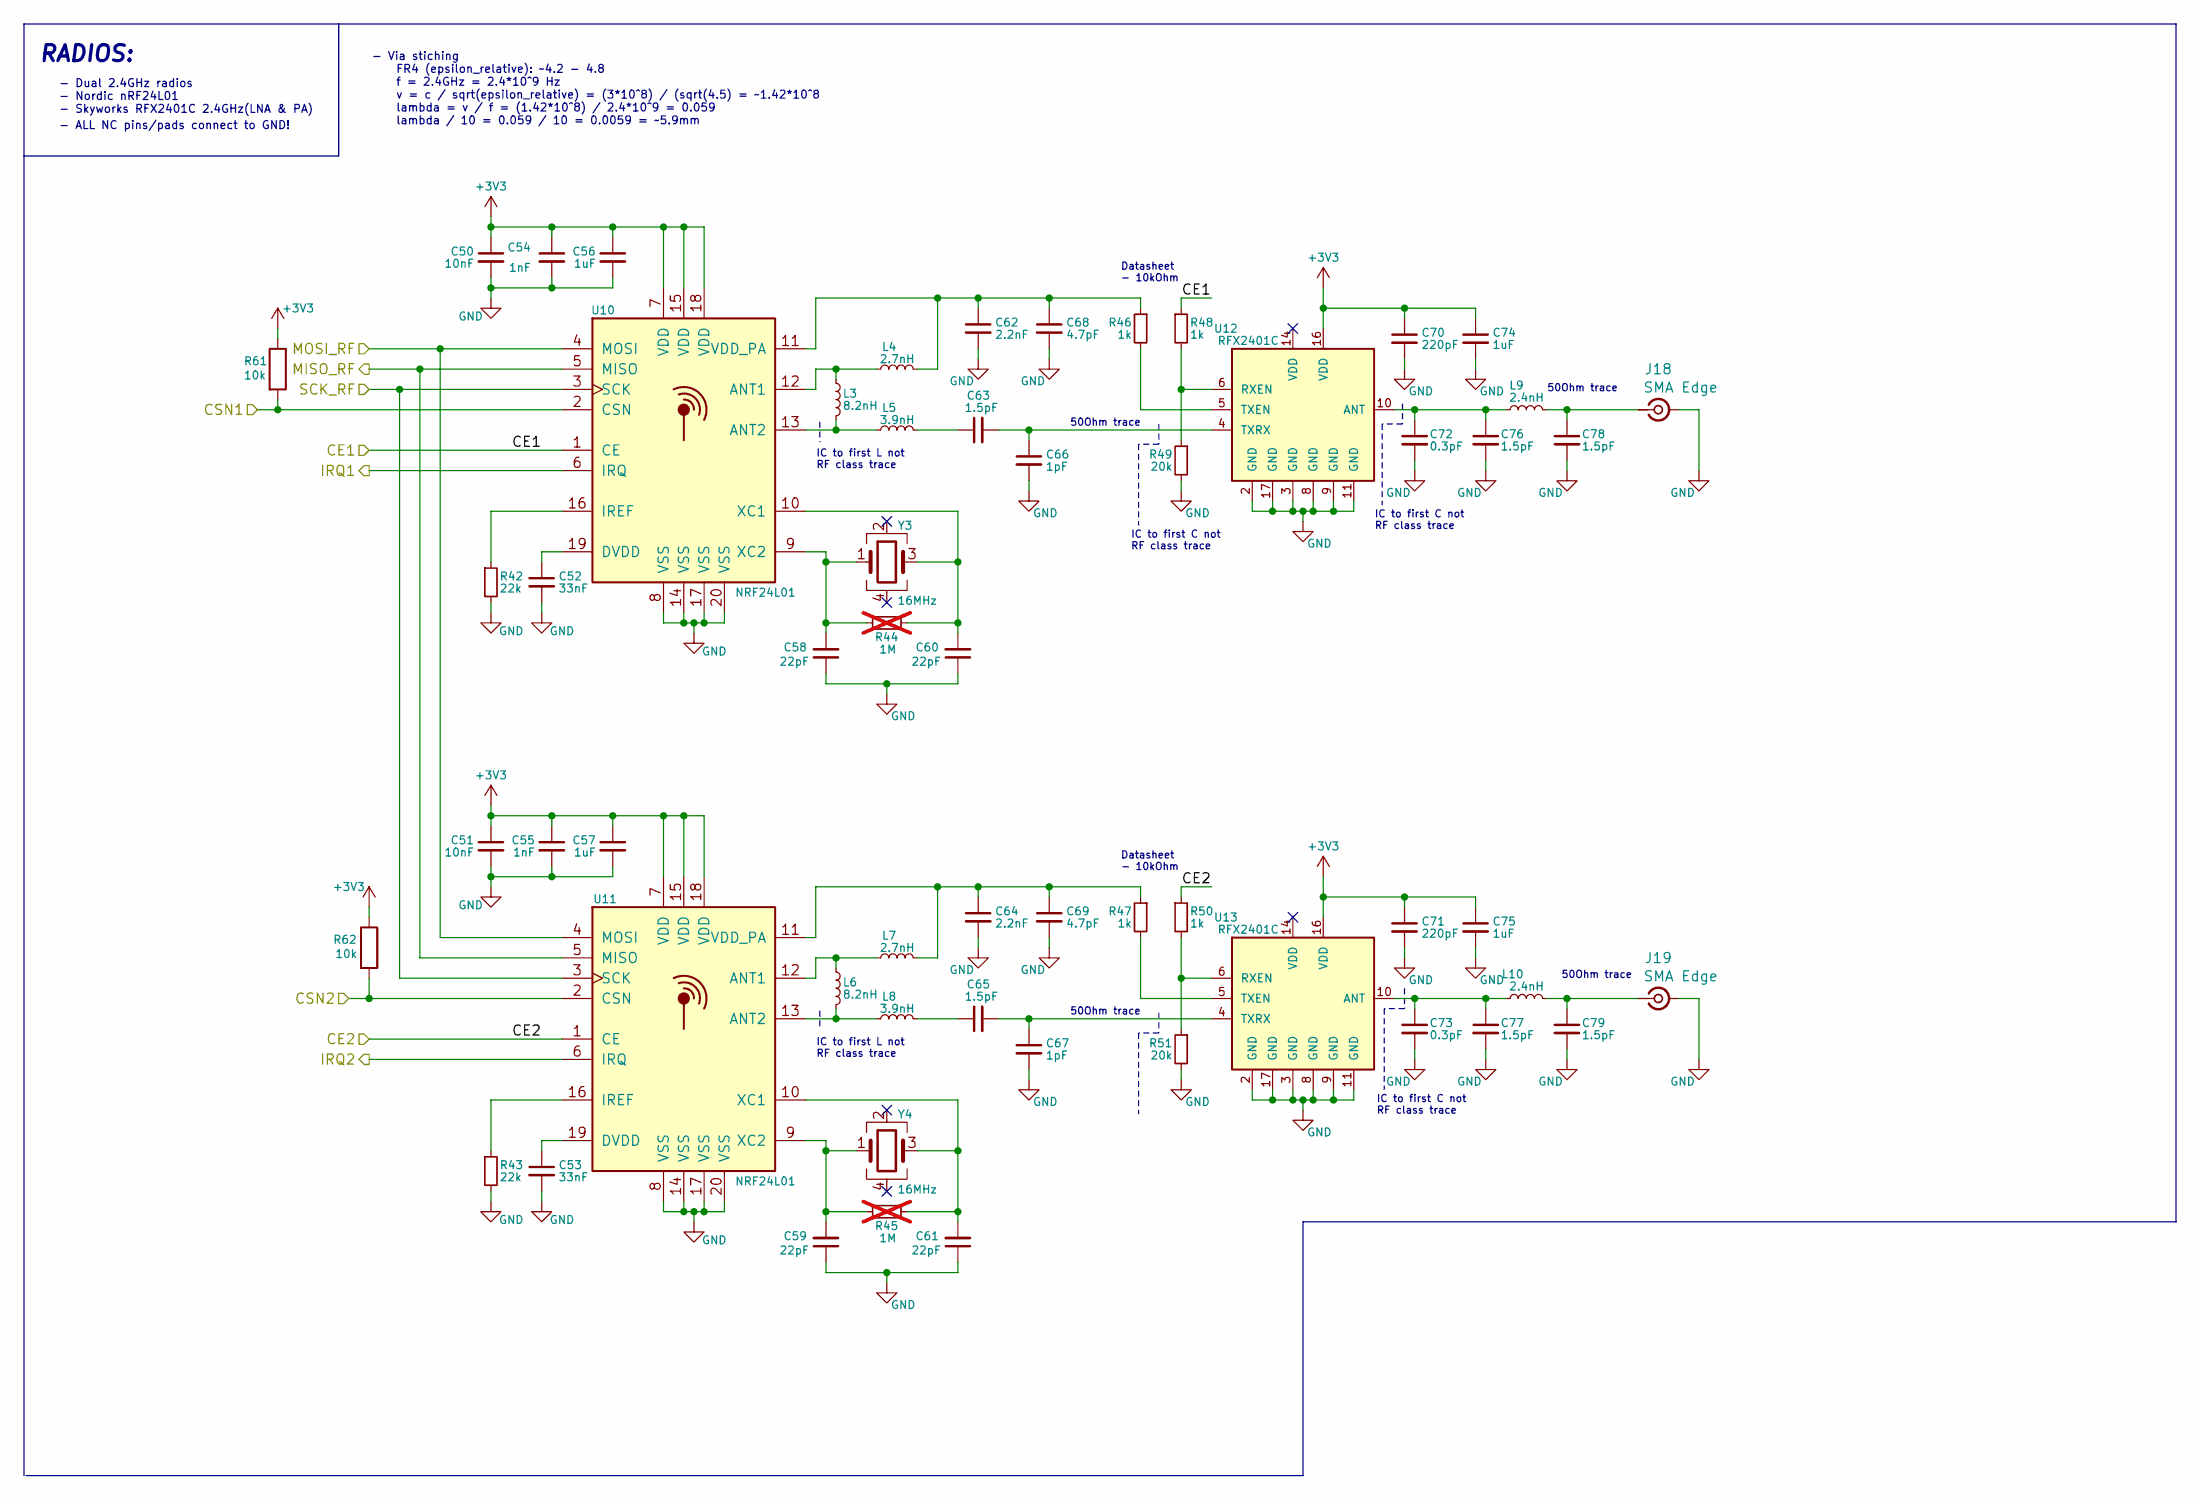
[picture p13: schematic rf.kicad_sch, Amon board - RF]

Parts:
C50, C51: 10nF; C_0402_1005Metric
C52, C53: 33nF; C_0402_1005Metric
C54, C55: 1nF; C_0402_1005Metric
C56, C57, C74, C75: 1uF; C_0402_1005Metric
C58, C59, C60, C61: 22pF; C_0402_1005Metric
C62, C64: 2.2nF; C_0402_1005Metric
C63, C65, C76, C77, C78, C79: 1.5pF; C_0402_1005Metric
C66, C67: 1pF; C_0402_1005Metric
C68, C69: 4.7pF; C_0402_1005Metric
C70, C71: 220pF; C_0402_1005Metric
C72, C73: 0.3pF; C_0402_1005Metric
J18, J19: SMA Edge; SMA_Amphenol_132289_EdgeMount
L3, L6: 8.2nH; L_0402_1005Metric
L4, L7: 2.7nH; L_0402_1005Metric
L5, L8: 3.9nH; L_0402_1005Metric
L9, L10: 2.4nH; L_0402_1005Metric
R42, R43: 22k; R_0402_1005Metric
R44, R45: 1M; R_0402_1005Metric; not fitted
R46, R47, R48, R50: 1k; R_0402_1005Metric
R49, R51: 20k; R_0402_1005Metric
R61, R62: 10k; R_0603_1608Metric
U10, U11: NRF24L01; QFN-20-1EP_4x4mm_P0.5mm_EP2.5x2.5mm
U12, U13: RFX2401C; QFN50P300X300X60-17N
Y3, Y4: 16MHz; Crystal_SMD_3225-4Pin_3.2x2.5mm

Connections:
+3V3: C50.1, C51.1, C54.1, C55.1, C56.1, C57.1, C70.1, C71.1, C74.1, C75.1, R61.1, R62.1, U10.7 (VDD), U10.15 (VDD), U10.18 (VDD), U11.7 (VDD), U11.15 (VDD), U11.18 (VDD), U12.16 (VDD), U13.16 (VDD); also elsewhere on the board
/Microcontroller/CSN1: R61.2, U10.2 (CSN); also elsewhere on the board
/Microcontroller/CSN2: R62.2, U11.2 (CSN); also elsewhere on the board
/Microcontroller/IRQ1: U10.6 (IRQ); also elsewhere on the board
/Microcontroller/IRQ2: U11.6 (IRQ); also elsewhere on the board
/Microcontroller/MISO_RF: U10.5 (MISO), U11.5 (MISO); also elsewhere on the board
/Microcontroller/MOSI_RF: U10.4 (MOSI), U11.4 (MOSI); also elsewhere on the board
/Microcontroller/SCK_RF: U10.3 (SCK), U11.3 (SCK); also elsewhere on the board
/RF/CE1: R48.1, U10.1 (CE); also elsewhere on the board
/RF/CE2: R50.1, U11.1 (CE); also elsewhere on the board
GND: C50.2, C51.2, C52.2, C53.2, C54.2, C55.2, C56.2, C57.2, C58.1, C59.1, C60.1, C61.1, C62.2, C64.2, C66.2, C67.2, C68.2, C69.2, C70.2, C71.2, C72.2, C73.2, C74.2, C75.2, C76.2, C77.2, C78.2, C79.2, J18.2 (Ext), J19.2 (Ext), R42.2, R43.2, R49.2, R51.2, U10.8 (VSS), U10.14 (VSS), U10.17 (VSS), U10.20 (VSS), U11.8 (VSS), U11.14 (VSS), U11.17 (VSS), U11.20 (VSS), U12.2 (GND), U12.3 (GND), U12.8 (GND), U12.9 (GND), U12.11 (GND), U12.17 (GND), U13.2 (GND), U13.3 (GND), U13.8 (GND), U13.9 (GND), U13.11 (GND), U13.17 (GND); also elsewhere on the board
unnamed: C63.1, L5.2
unnamed: C65.1, L8.2
unnamed: C78.1, J18.1 (In), L9.2
unnamed: C79.1, J19.1 (In), L10.2
unnamed: L3.1, L4.1, U10.12 (ANT1)
unnamed: L3.2, L5.1, U10.13 (ANT2)
unnamed: C52.1, U10.19 (DVDD)
unnamed: R42.1, U10.16 (IREF)
unnamed: C62.1, C68.1, L4.2, R46.1, U10.11 (VDD_PA)
unnamed: C60.2, R44.2, U10.10 (XC1), Y3.3
unnamed: C58.2, R44.1, U10.9 (XC2), Y3.1
unnamed: L6.1, L7.1, U11.12 (ANT1)
unnamed: L6.2, L8.1, U11.13 (ANT2)
unnamed: C53.1, U11.19 (DVDD)
unnamed: R43.1, U11.16 (IREF)
unnamed: C64.1, C69.1, L7.2, R47.1, U11.11 (VDD_PA)
unnamed: C61.2, R45.2, U11.10 (XC1), Y4.3
unnamed: C59.2, R45.1, U11.9 (XC2), Y4.1
unnamed: C72.1, C76.1, L9.1, U12.10 (ANT)
unnamed: R48.2, R49.1, U12.6 (RXEN)
unnamed: R46.2, U12.5 (TXEN)
unnamed: C63.2, C66.1, U12.4 (TXRX)
unnamed: C73.1, C77.1, L10.1, U13.10 (ANT)
unnamed: R50.2, R51.1, U13.6 (RXEN)
unnamed: R47.2, U13.5 (TXEN)
unnamed: C65.2, C67.1, U13.4 (TXRX)

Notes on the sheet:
50Ohm trace
- ALL NC pins/pads connect to GND!
IC to first C not RF class trace
- Dual 2.4GHz radios - Nordic nRF24L01 - Skyworks RFX2401C 2.4GHz(LNA & PA)
Datasheet - 10kOhm
- Via stiching FR4 (epsilon_relative): ~4.2 - 4.8 f = 2.4GHz = 2.4*10^9 Hz v = c / sqrt(epsilon_relative) = (3*10^8) / (sqrt(4.5) = ~1.42*10^8 lambda = v / f = (1.42*10^8) / 2.4*10^9 = 0.059 lambda / 10 = 0.059 / 10 = 0.0059 = ~5.9mm
RADIOS:
IC to first L not RF class trace

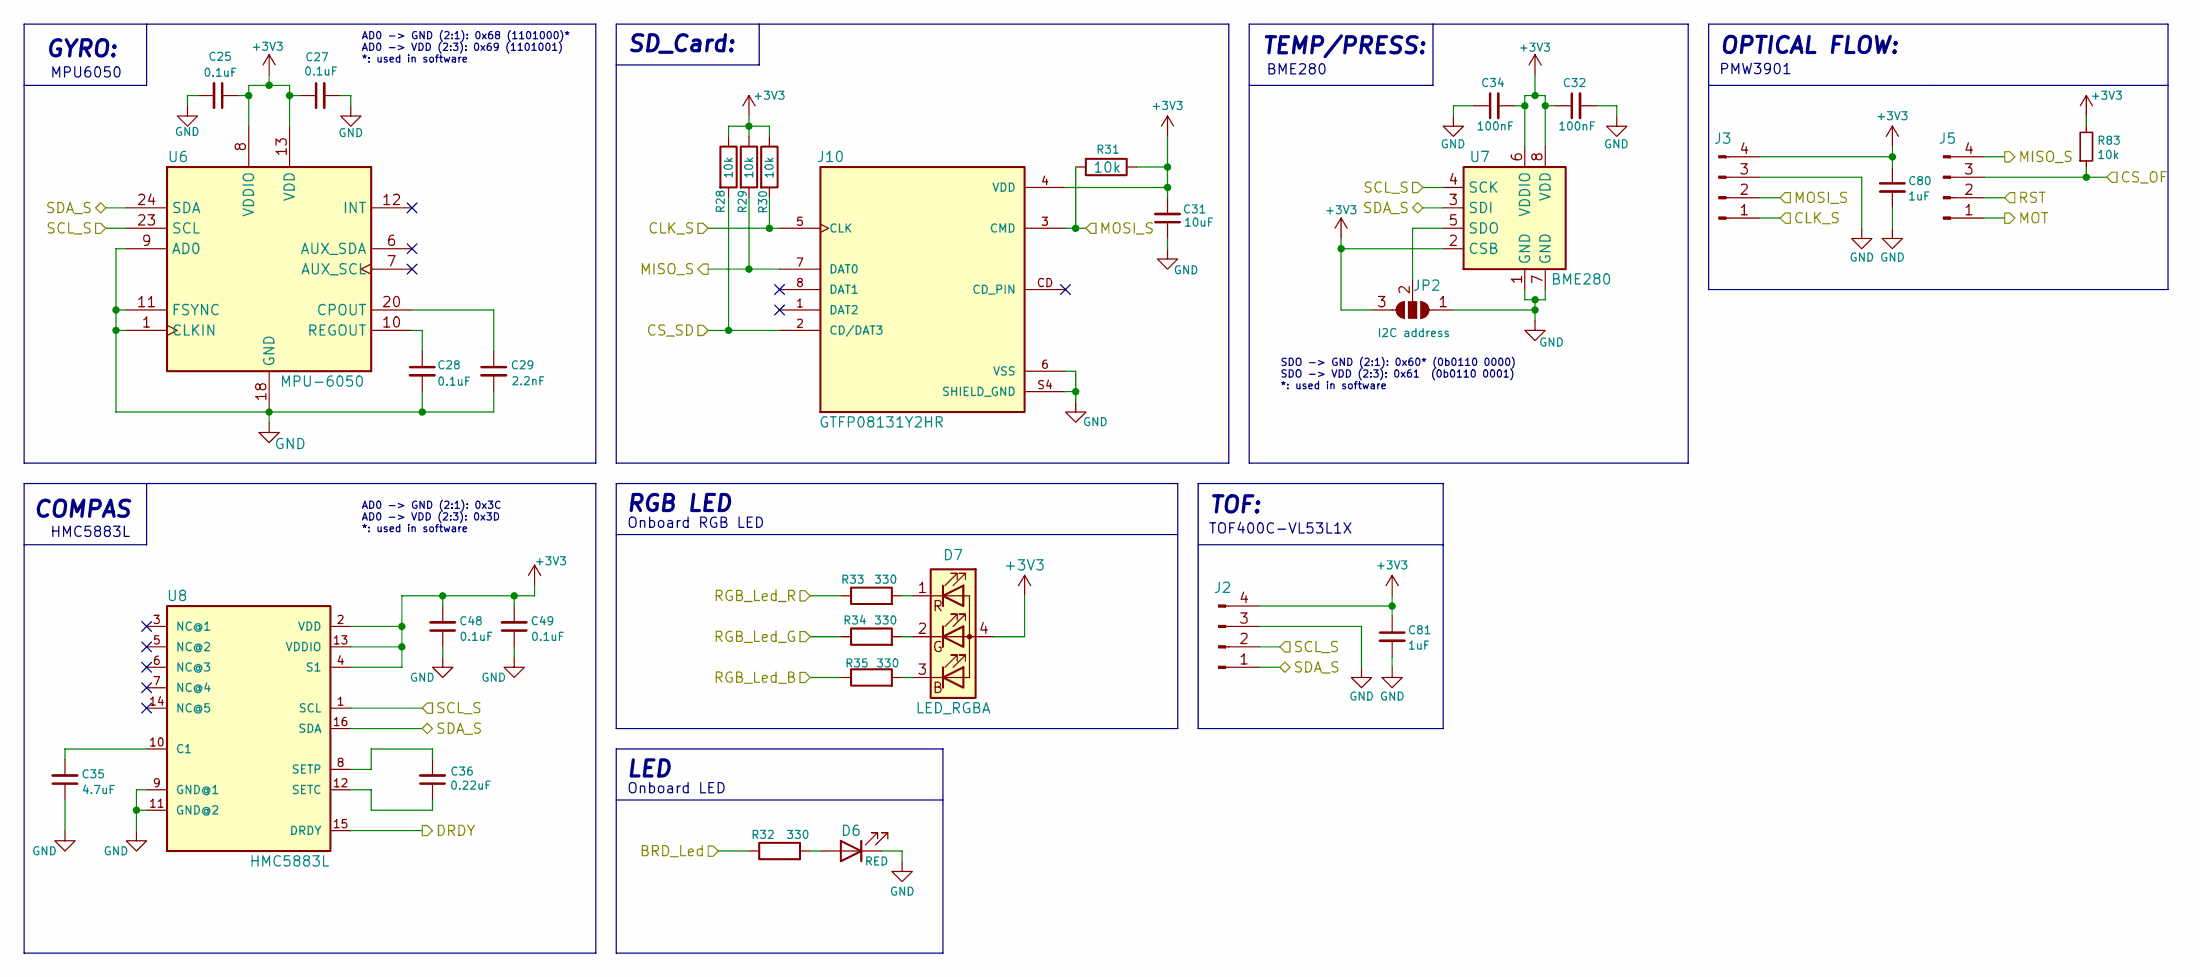
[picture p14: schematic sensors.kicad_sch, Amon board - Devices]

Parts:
C25, C27, C28, C48, C49: 0.1uF; C_0603_1608Metric
C29: 2.2nF; C_0603_1608Metric
C31: 10uF; C_0603_1608Metric
C32, C34: 100nF; C_0603_1608Metric
C35: 4.7uF; C_0603_1608Metric
C36: 0.22uF; C_0603_1608Metric
C80, C81: 1uF; C_0603_1608Metric
D6: RED; LED_0603_1608Metric
D7: LED_RGBA; LED_Cree-PLCC4_3.2x2.8mm_CCW
J2, J3, J5: Conn_01x04_Pin; JST_EH_S4B-EH_1x04_P2.50mm_Horizontal
J10: GTFP08131Y2HR; AMPHENOL_GTFP08131Y2HR; PARTREV A
JP2: I2C address; SolderJumper-3_P1.3mm_Open_RoundedPad1.0x1.5mm_NumberLabels
R28, R29, R30, R31, R83: 10k; R_0603_1608Metric
R32, R33, R34, R35: 330; R_0603_1608Metric
U6: MPU-6050; InvenSense_QFN-24_4x4mm_P0.5mm
U7: BME280; Bosch_LGA-8_2x2.5mm_P0.65mm_ClockwisePinNumbering
U8: HMC5883L; LPCC-16

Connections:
+3V3: C25.1, C27.1, C31.2, C32.1, C34.2, C48.2, C49.2, C80.1, C81.1, D7.4 (A), J2.4, J3.4, J10.4 (VDD), JP2.3 (B), R28.1, R29.1, R30.1, R31.1, R83.2, U6.8 (VDDIO), U6.13 (VDD), U7.2 (CSB), U7.6 (VDDIO), U7.8 (VDD), U8.2 (VDD), U8.4 (S1), U8.13 (VDDIO); also elsewhere on the board
/Devices/BRD_Led: R32.1; also elsewhere on the board
/Devices/CLK_S: J3.1, J10.5 (CLK), R30.2; also elsewhere on the board
/Devices/CS_OF: J5.3, R83.1; also elsewhere on the board
/Devices/CS_SD: J10.2 (CD/DAT3), R28.2; also elsewhere on the board
/Devices/DRDY: U8.15 (DRDY); also elsewhere on the board
/Devices/MISO_S: J5.4, J10.7 (DAT0), R29.2; also elsewhere on the board
/Devices/MOSI_S: J3.2, J10.3 (CMD), R31.2; also elsewhere on the board
/Devices/MOT: J5.1; also elsewhere on the board
/Devices/RGB_Led_B: R35.1; also elsewhere on the board
/Devices/RGB_Led_G: R34.1; also elsewhere on the board
/Devices/RGB_Led_R: R33.1; also elsewhere on the board
/Devices/RST: J5.2; also elsewhere on the board
/Devices/SCL_S: J2.2, U6.23 (SCL), U7.4 (SCK), U8.1 (SCL); also elsewhere on the board
/Devices/SDA_S: J2.1, U6.24 (SDA), U7.3 (SDI), U8.16 (SDA); also elsewhere on the board
GND: C25.2, C27.2, C28.2, C29.2, C31.1, C32.2, C34.1, C35.1, C48.1, C49.1, C80.2, C81.2, D6.1 (K), J2.3, J3.3, J10.6 (VSS), J10.S4 (SHIELD_GND), JP2.1 (A), U6.1 (CLKIN), U6.9 (AD0), U6.11 (FSYNC), U6.18 (GND), U7.1 (GND), U7.7 (GND), U8.9 (GND@1), U8.11 (GND@2); also elsewhere on the board
unnamed: D6.2 (A), R32.2
unnamed: D7.3 (BK), R35.2
unnamed: D7.2 (GK), R34.2
unnamed: D7.1 (RK), R33.2
unnamed: JP2.2 (C), U7.5 (SDO)
unnamed: C29.1, U6.20 (CPOUT)
unnamed: C28.1, U6.10 (REGOUT)
unnamed: C35.2, U8.10 (C1)
unnamed: C36.1, U8.12 (SETC)
unnamed: C36.2, U8.8 (SETP)

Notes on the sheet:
COMPAS
GYRO:
TOF:
AD0 -> GND (2:1): 0x3C AD0 -> VDD (2:3): 0x3D *: used in software
Onboard RGB LED
TEMP/PRESS:
AD0 -> GND (2:1): 0x68 (1101000)* AD0 -> VDD (2:3): 0x69 (1101001) *: used in software
LED
OPTICAL FLOW:
Onboard LED
HMC5883L
RGB LED
SD_Card:
PMW3901
SDO -> GND (2:1): 0x60* (0b0110 0000) SDO -> VDD (2:3): 0x61 (0b0110 0001) *: used in software
MPU6050
BME280
TOF400C-VL53L1X

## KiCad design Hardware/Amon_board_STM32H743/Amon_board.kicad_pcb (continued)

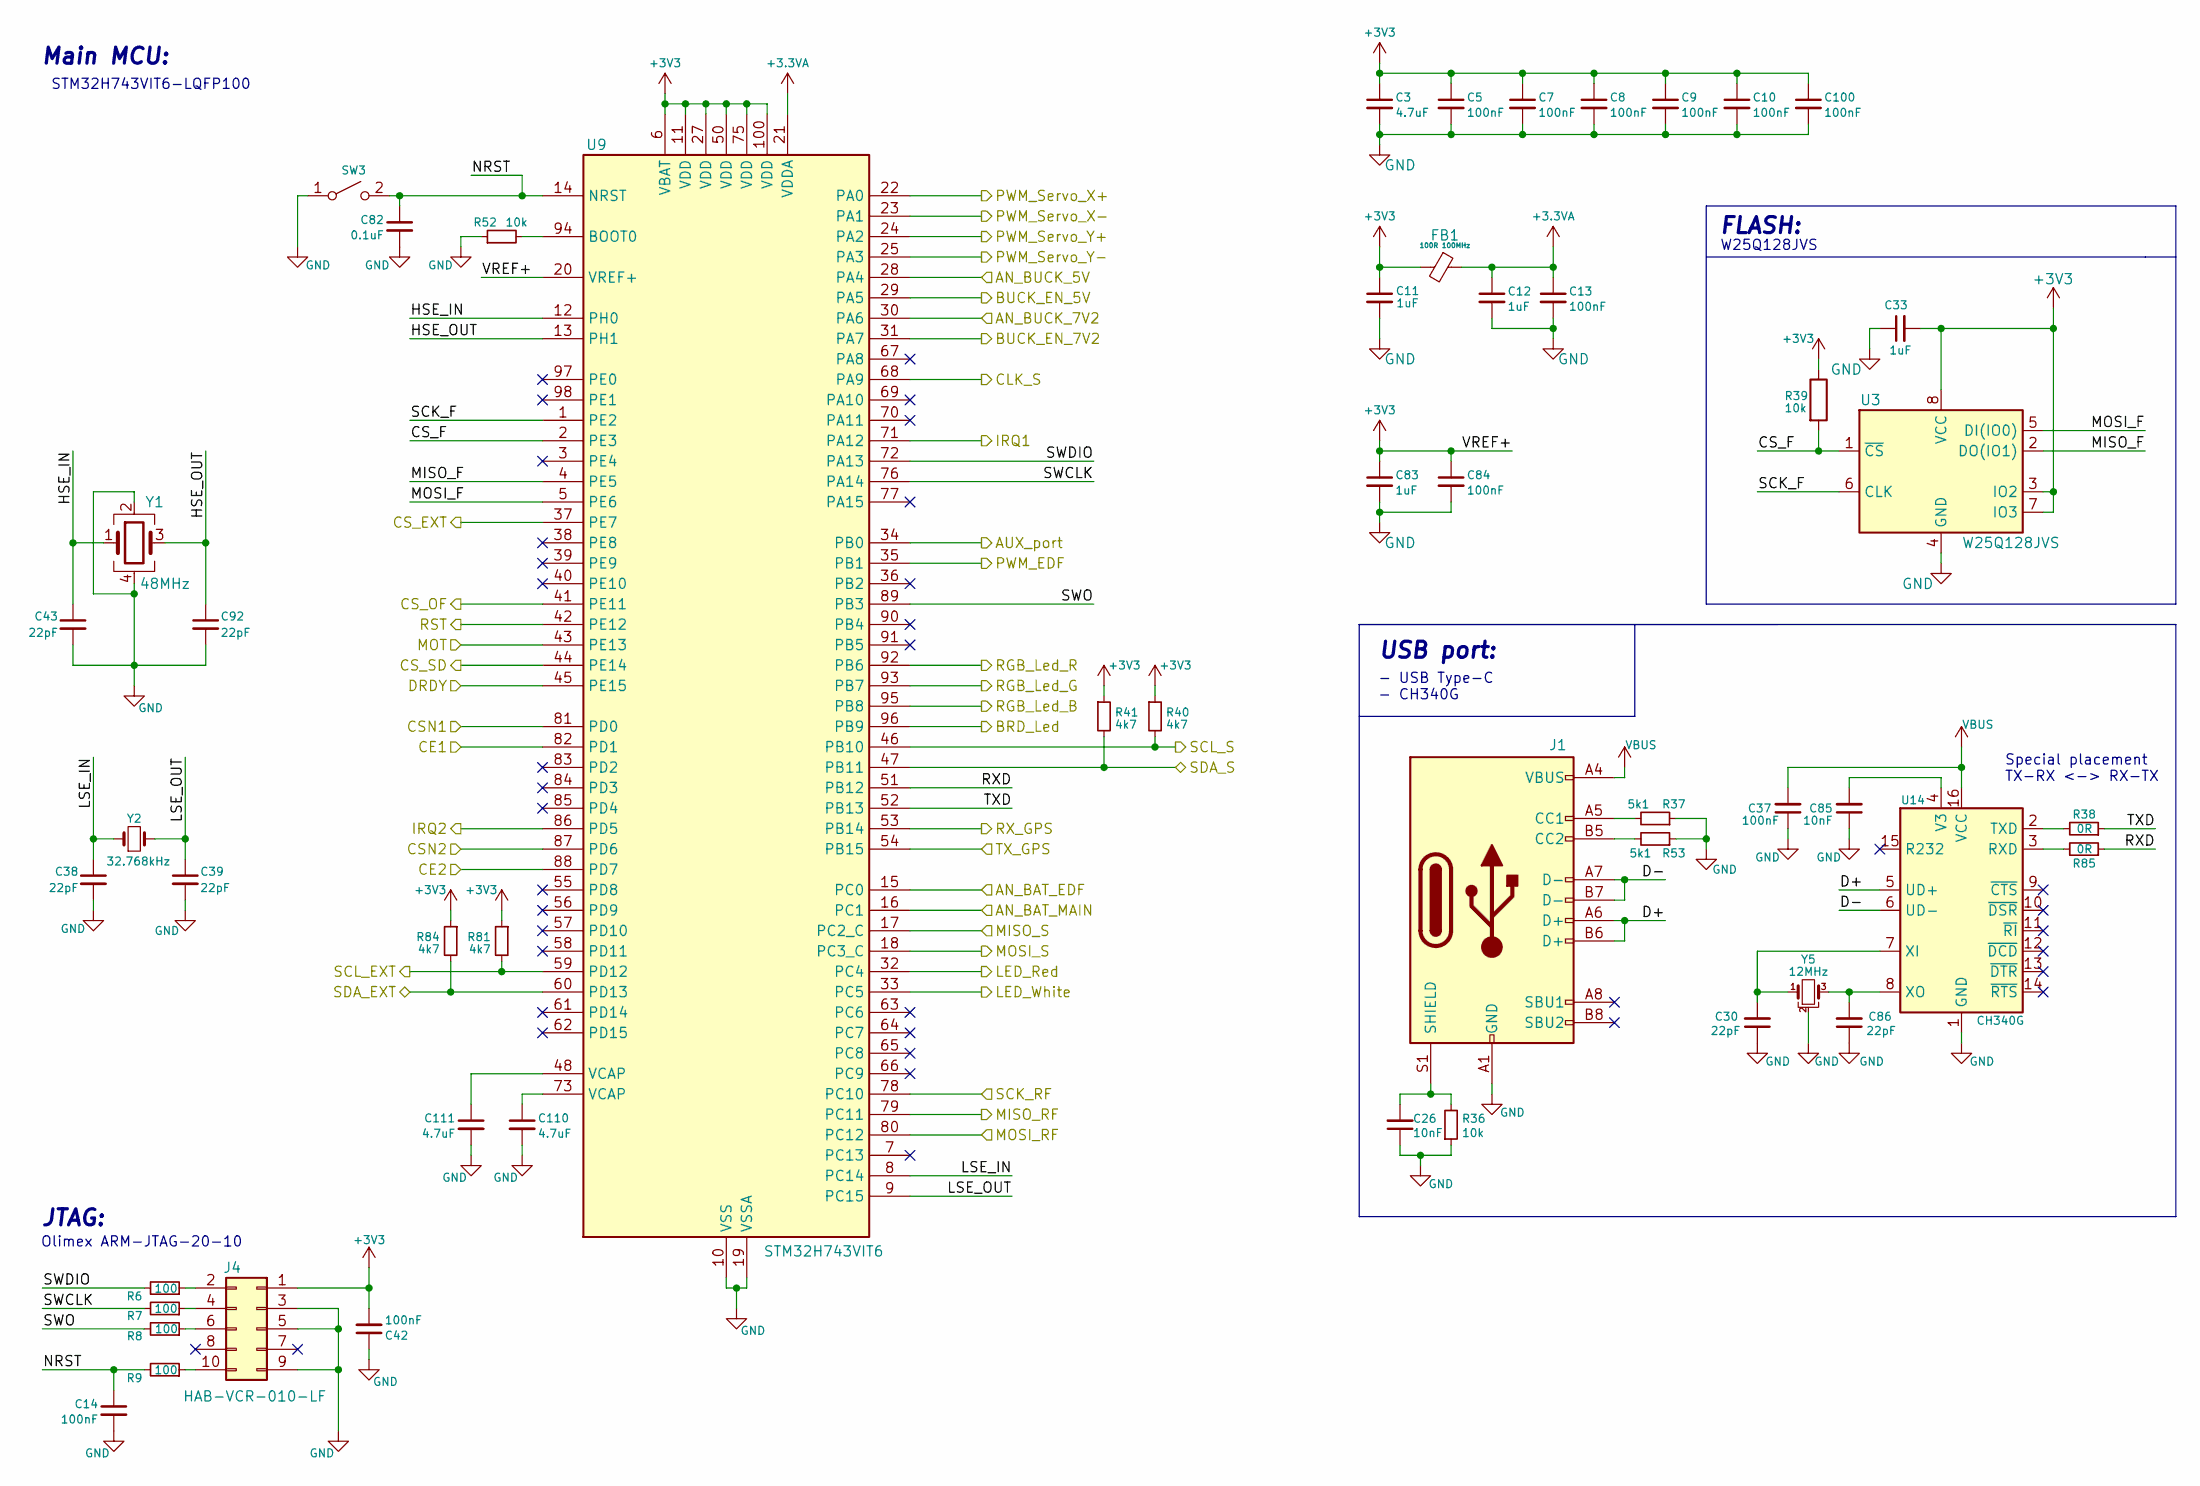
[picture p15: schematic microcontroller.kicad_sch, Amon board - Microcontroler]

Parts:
C3, C110, C111: 4.7uF; C_0603_1608Metric
C5, C7, C8, C9, C10, C13, C14, C37, C42, C84, C100: 100nF; C_0603_1608Metric
C11, C12, C33, C83: 1uF; C_0603_1608Metric
C26, C85: 10nF; C_0603_1608Metric
C30, C38, C39, C43, C86, C92: 22pF; C_0402_1005Metric
C82: 0.1uF; C_0603_1608Metric
FB1: 100R 100MHz; L_1206_3216Metric_Pad1.22x1.90mm_HandSolder
J1: USB_C_Receptacle_USB2.0; USB_C_Receptacle_XKB_U262-16XN-4BVC11
J4: HAB-VCR-010-LF; PinHeader_2x05_P1.27mm_Vertical_SMD
R6, R7, R8, R9: 100; R_0603_1608Metric
R36, R39, R52: 10k; R_0603_1608Metric
R37, R53: 5k1; R_0603_1608Metric
R38, R85: 0R; R_0603_1608Metric
R40, R41, R81, R84: 4k7; R_0603_1608Metric
SW3: SW_SPST; SW_Push_1P1T_NO_CK_KMR2
U3: W25Q128JVS; SOIC-8_5.23x5.23mm_P1.27mm
U9: STM32H743VIT6; LQFP-100_14x14mm_P0.5mm
U14: CH340G; SOIC-16_3.9x9.9mm_P1.27mm
Y1: 48MHz; Crystal_SMD_3225-4Pin_3.2x2.5mm
Y2: 32.768kHz; Crystal_SMD_3215-2Pin_3.2x1.5mm
Y5: 12MHz; Resonator_SMD_Murata_CSTxExxV-3Pin_3.0x1.1mm

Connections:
+3.3VA: C12.1, C13.1, FB1.1, U9.21 (VDDA)
+3V3: C3.1, C5.1, C7.1, C8.1, C9.1, C10.1, C11.1, C33.2, C42.2, C83.1, C84.1, C100.1, FB1.2, J4.1, R39.1, R40.1, R41.1, R81.1, R84.1, U3.3 (IO2), U3.7 (IO3), U3.8 (VCC), U9.6 (VBAT), U9.11 (VDD), U9.20 (VREF+), U9.27 (VDD), U9.50 (VDD), U9.75 (VDD), U9.100 (VDD); also elsewhere on the board
/Devices/BRD_Led: U9.96 (PB9); also elsewhere on the board
/Devices/CLK_S: U9.68 (PA9); also elsewhere on the board
/Devices/CS_OF: U9.41 (PE11); also elsewhere on the board
/Devices/CS_SD: U9.44 (PE14); also elsewhere on the board
/Devices/DRDY: U9.45 (PE15); also elsewhere on the board
/Devices/MISO_S: U9.17 (PC2_C); also elsewhere on the board
/Devices/MOSI_S: U9.18 (PC3_C); also elsewhere on the board
/Devices/MOT: U9.43 (PE13); also elsewhere on the board
/Devices/RGB_Led_B: U9.95 (PB8); also elsewhere on the board
/Devices/RGB_Led_G: U9.93 (PB7); also elsewhere on the board
/Devices/RGB_Led_R: U9.92 (PB6); also elsewhere on the board
/Devices/RST: U9.42 (PE12); also elsewhere on the board
/Devices/SCL_S: R40.2, U9.46 (PB10); also elsewhere on the board
/Devices/SDA_S: R41.2, U9.47 (PB11); also elsewhere on the board
/Microcontroller/AN_BAT_EDF: U9.15 (PC0); also elsewhere on the board
/Microcontroller/AN_BAT_MAIN: U9.16 (PC1); also elsewhere on the board
/Microcontroller/AN_BUCK_5V: U9.28 (PA4); also elsewhere on the board
/Microcontroller/AN_BUCK_7V2: U9.30 (PA6); also elsewhere on the board
/Microcontroller/AUX_port: U9.34 (PB0); also elsewhere on the board
/Microcontroller/BUCK_EN_5V: U9.29 (PA5); also elsewhere on the board
/Microcontroller/BUCK_EN_7V2: U9.31 (PA7); also elsewhere on the board
/Microcontroller/CSN1: U9.81 (PD0); also elsewhere on the board
/Microcontroller/CSN2: U9.87 (PD6); also elsewhere on the board
/Microcontroller/CS_EXT: U9.37 (PE7); also elsewhere on the board
/Microcontroller/CS_F: R39.2, U3.1 (~CS), U9.2 (PE3)
/Microcontroller/D+: J1.A6 (D+), J1.B6 (D+), U14.5 (UD+)
/Microcontroller/D-: J1.A7 (D-), J1.B7 (D-), U14.6 (UD-)
/Microcontroller/HSE_IN: C43.1, U9.12 (PH0), Y1.1
/Microcontroller/HSE_OUT: C92.1, U9.13 (PH1), Y1.3
/Microcontroller/IRQ1: U9.71 (PA12); also elsewhere on the board
/Microcontroller/IRQ2: U9.86 (PD5); also elsewhere on the board
/Microcontroller/LED_Red: U9.32 (PC4); also elsewhere on the board
/Microcontroller/LED_White: U9.33 (PC5); also elsewhere on the board
/Microcontroller/LSE_IN: C38.1, U9.8 (PC14), Y2.1
/Microcontroller/LSE_OUT: C39.1, U9.9 (PC15), Y2.2
/Microcontroller/MISO_F: U3.2 (DO(IO1)), U9.4 (PE5)
/Microcontroller/MISO_RF: U9.79 (PC11); also elsewhere on the board
/Microcontroller/MOSI_F: U3.5 (DI(IO0)), U9.5 (PE6)
/Microcontroller/MOSI_RF: U9.80 (PC12); also elsewhere on the board
/Microcontroller/NRST: C14.1, C82.1, R9.2, SW3.2 (B), U9.14 (NRST)
/Microcontroller/PWM_EDF: U9.35 (PB1); also elsewhere on the board
/Microcontroller/PWM_Servo_X+: U9.22 (PA0); also elsewhere on the board
/Microcontroller/PWM_Servo_X-: U9.23 (PA1); also elsewhere on the board
/Microcontroller/PWM_Servo_Y+: U9.24 (PA2); also elsewhere on the board
/Microcontroller/PWM_Servo_Y-: U9.25 (PA3); also elsewhere on the board
/Microcontroller/RXD: R85.1, U9.51 (PB12)
/Microcontroller/RX_GPS: U9.53 (PB14); also elsewhere on the board
/Microcontroller/SCK_F: U3.6 (CLK), U9.1 (PE2)
/Microcontroller/SCK_RF: U9.78 (PC10); also elsewhere on the board
/Microcontroller/SCL_EXT: R81.2, U9.59 (PD12); also elsewhere on the board
/Microcontroller/SDA_EXT: R84.2, U9.60 (PD13); also elsewhere on the board
/Microcontroller/SWCLK: R7.2, U9.76 (PA14)
/Microcontroller/SWDIO: R6.2, U9.72 (PA13)
/Microcontroller/SWO: R8.2, U9.89 (PB3)
/Microcontroller/TXD: R38.1, U9.52 (PB13)
/Microcontroller/TX_GPS: U9.54 (PB15); also elsewhere on the board
/RF/CE1: U9.82 (PD1); also elsewhere on the board
/RF/CE2: U9.88 (PD7); also elsewhere on the board
GND: C3.2, C5.2, C7.2, C8.2, C9.2, C10.2, C11.2, C12.2, C13.2, C14.2, C26.1, C30.1, C33.1, C37.1, C38.2, C39.2, C42.1, C43.2, C82.2, C83.2, C84.2, C85.1, C86.1, C92.2, C100.2, C110.2, C111.2, J1.A1 (GND), J1.A12 (GND), J1.B1 (GND), J1.B12 (GND), J4.3, J4.5, J4.9, R36.1, R37.1, R52.1, R53.1, SW3.1 (A), U3.4 (GND), U9.10 (VSS), U9.19 (VSSA), U9.26 (VSS), U9.49 (VSS), U9.74 (VSS), U9.99 (VSS), U14.1 (GND), Y1.2, Y1.4, Y5.2; also elsewhere on the board
unnamed: C110.1, U9.73 (VCAP)
unnamed: C111.1, U9.48 (VCAP)
unnamed: J1.A5 (CC1), R37.2
unnamed: J1.B5 (CC2), R53.2
unnamed: C26.2, J1.S1 (SHIELD), R36.2
unnamed: J4.2, R6.1
unnamed: J4.4, R7.1
unnamed: J4.6, R8.1
unnamed: J4.10, R9.1
unnamed: R52.2, U9.94 (BOOT0)
unnamed: R85.2, U14.3 (RXD)
unnamed: R38.2, U14.2 (TXD)
unnamed: C85.2, U14.4 (V3)
unnamed: C30.2, U14.7 (XI), Y5.1
unnamed: C86.2, U14.8 (XO), Y5.3
VBUS: C37.2, J1.A4 (VBUS), J1.A9 (VBUS), J1.B4 (VBUS), J1.B9 (VBUS), U14.16 (VCC)

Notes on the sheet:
- USB Type-C - CH340G
USB port:
Main MCU:
JTAG:
Olimex ARM-JTAG-20-10
W25Q128JVS
STM32H743VIT6-LQFP100
FLASH:
Special placement TX-RX <-> RX-TX

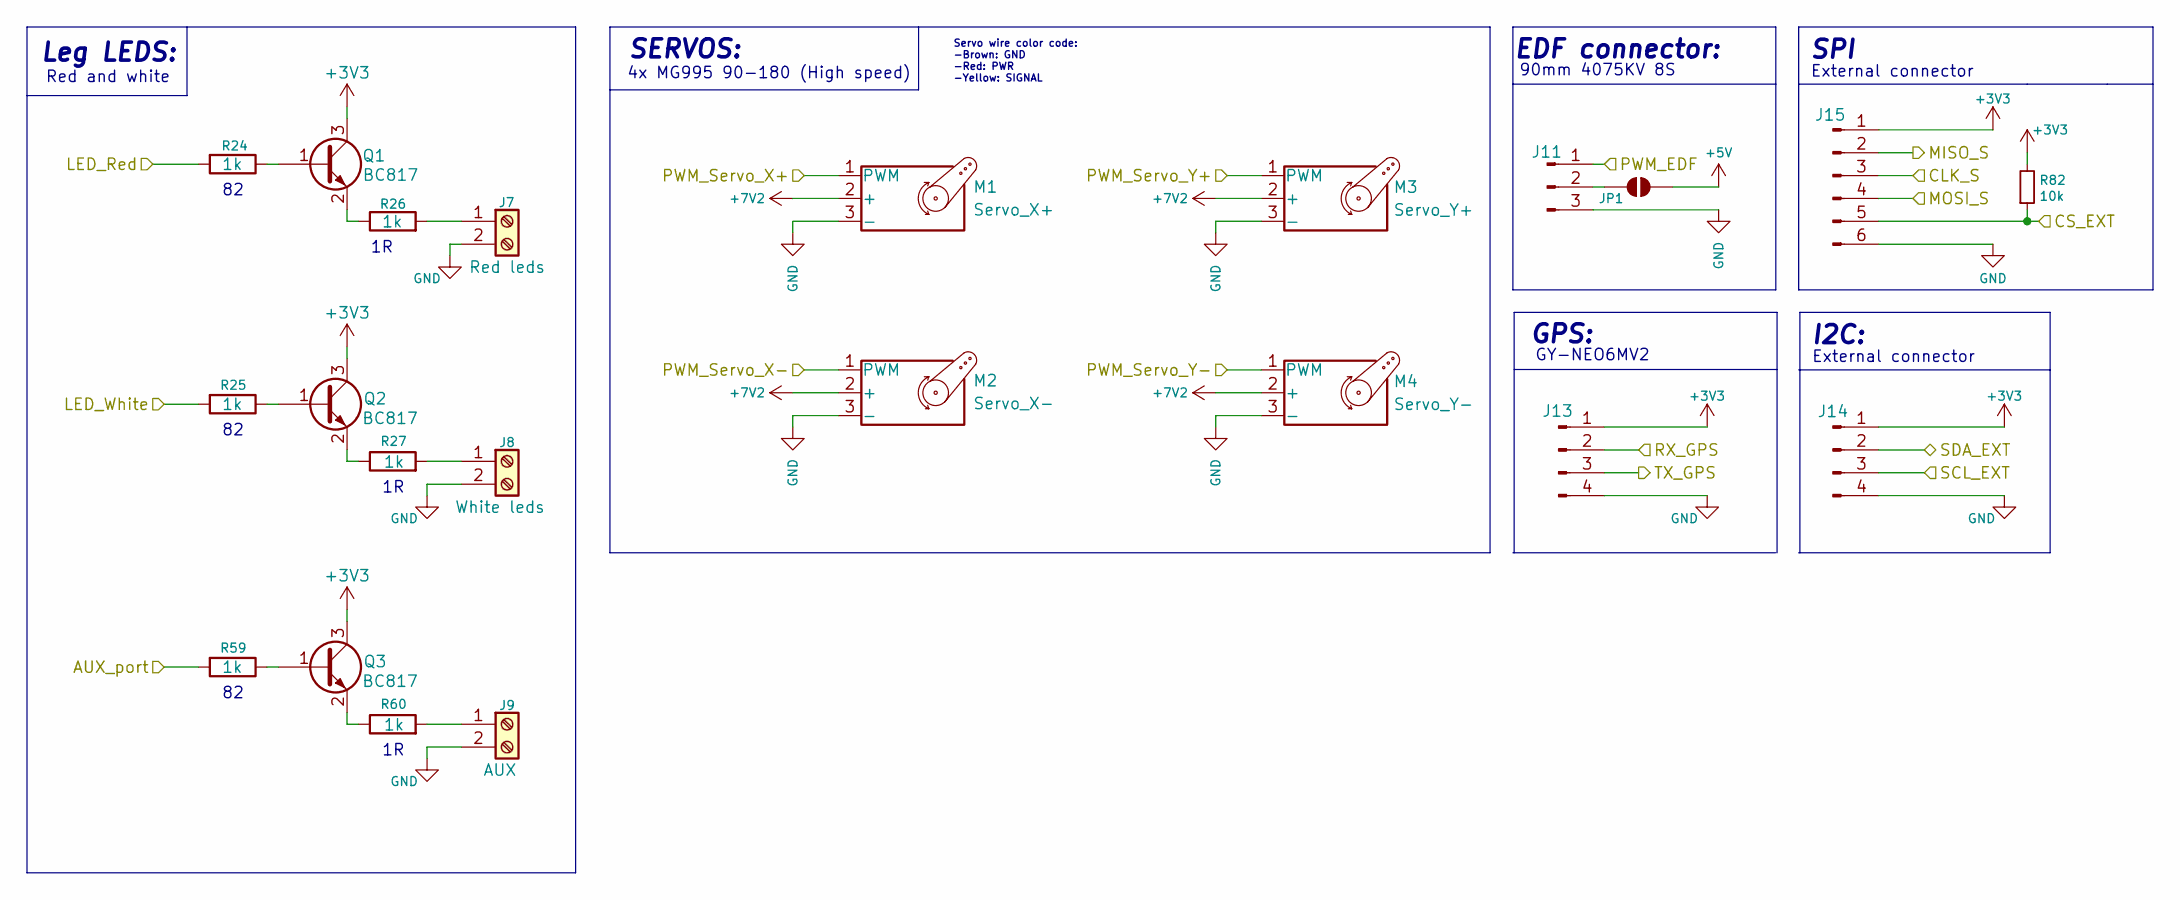
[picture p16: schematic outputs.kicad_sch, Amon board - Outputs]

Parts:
J7: Red leds; TerminalBlock_MetzConnect_Type059_RT06302HBWC_1x02_P3.50mm_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
J8: White leds; TerminalBlock_MetzConnect_Type059_RT06302HBWC_1x02_P3.50mm_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
J9: AUX; TerminalBlock_MetzConnect_Type059_RT06302HBWC_1x02_P3.50mm_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
J11: Conn_01x03_Male; PinHeader_1x03_P2.54mm_Vertical
J13: Conn_01x04_Male; JST_XH_S4B-XH-A_1x04_P2.50mm_Horizontal
J14: Conn_01x04_Male; PinHeader_1x04_P2.54mm_Vertical
J15: Conn_01x06_Male; PinHeader_1x06_P2.54mm_Vertical
JP1: SolderJumper_2_Open; SolderJumper-2_P1.3mm_Open_RoundedPad1.0x1.5mm
M1: Servo_X+; PinHeader_1x03_P2.54mm_Vertical
M2: Servo_X-; PinHeader_1x03_P2.54mm_Vertical
M3: Servo_Y+; PinHeader_1x03_P2.54mm_Vertical
M4: Servo_Y-; PinHeader_1x03_P2.54mm_Vertical
Q1, Q2, Q3: BC817; SOT-23
R24, R25, R26, R27, R59, R60: 1k; R_0603_1608Metric
R82: 10k; R_0603_1608Metric

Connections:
+3V3: J13.1, J14.1, J15.1, Q1.3 (C), Q2.3 (C), Q3.3 (C), R82.2; also elsewhere on the board
+5V: JP1.2 (B); also elsewhere on the board
+7V2: M1.2 (+), M2.2 (+), M3.2 (+), M4.2 (+); also elsewhere on the board
/Devices/CLK_S: J15.3; also elsewhere on the board
/Devices/MISO_S: J15.2; also elsewhere on the board
/Devices/MOSI_S: J15.4; also elsewhere on the board
/Microcontroller/AUX_port: R59.2; also elsewhere on the board
/Microcontroller/CS_EXT: J15.5, R82.1; also elsewhere on the board
/Microcontroller/LED_Red: R24.2; also elsewhere on the board
/Microcontroller/LED_White: R25.2; also elsewhere on the board
/Microcontroller/PWM_EDF: J11.1; also elsewhere on the board
/Microcontroller/PWM_Servo_X+: M1.1 (PWM); also elsewhere on the board
/Microcontroller/PWM_Servo_X-: M2.1 (PWM); also elsewhere on the board
/Microcontroller/PWM_Servo_Y+: M3.1 (PWM); also elsewhere on the board
/Microcontroller/PWM_Servo_Y-: M4.1 (PWM); also elsewhere on the board
/Microcontroller/RX_GPS: J13.2; also elsewhere on the board
/Microcontroller/SCL_EXT: J14.3; also elsewhere on the board
/Microcontroller/SDA_EXT: J14.2; also elsewhere on the board
/Microcontroller/TX_GPS: J13.3; also elsewhere on the board
GND: J7.2, J8.2, J9.2, J11.3, J13.4, J14.4, J15.6, M1.3 (-), M2.3 (-), M3.3 (-), M4.3 (-); also elsewhere on the board
unnamed: J7.1, R26.2
unnamed: J8.1, R27.2
unnamed: J9.1, R60.2
unnamed: J11.2, JP1.1 (A)
unnamed: Q1.1 (B), R24.1
unnamed: Q1.2 (E), R26.1
unnamed: Q2.1 (B), R25.1
unnamed: Q2.2 (E), R27.1
unnamed: Q3.1 (B), R59.1
unnamed: Q3.2 (E), R60.1

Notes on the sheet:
SPI
90mm 4075KV 8S
4x MG995 90-180 (High speed)
External connector
Red and white
EDF connector:
Leg LEDS:
SERVOS:
Servo wire color code: -Brown: GND -Red: PWR -Yellow: SIGNAL
GPS:
I2C:
GY-NEO6MV2

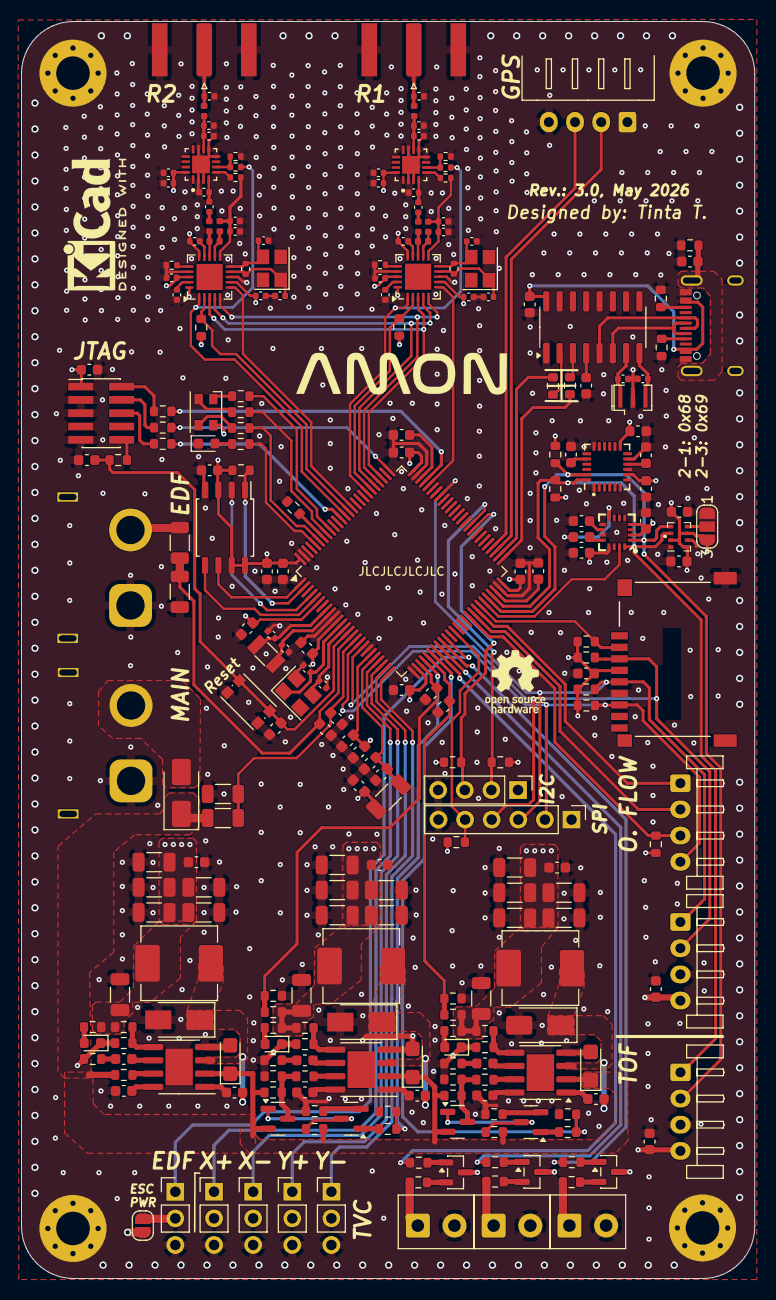
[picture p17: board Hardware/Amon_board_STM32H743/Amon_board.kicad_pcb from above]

Board: 4 copper layers, 70.0 x 120.0 mm, 259 parts (0 on the bottom side), 160 nets.

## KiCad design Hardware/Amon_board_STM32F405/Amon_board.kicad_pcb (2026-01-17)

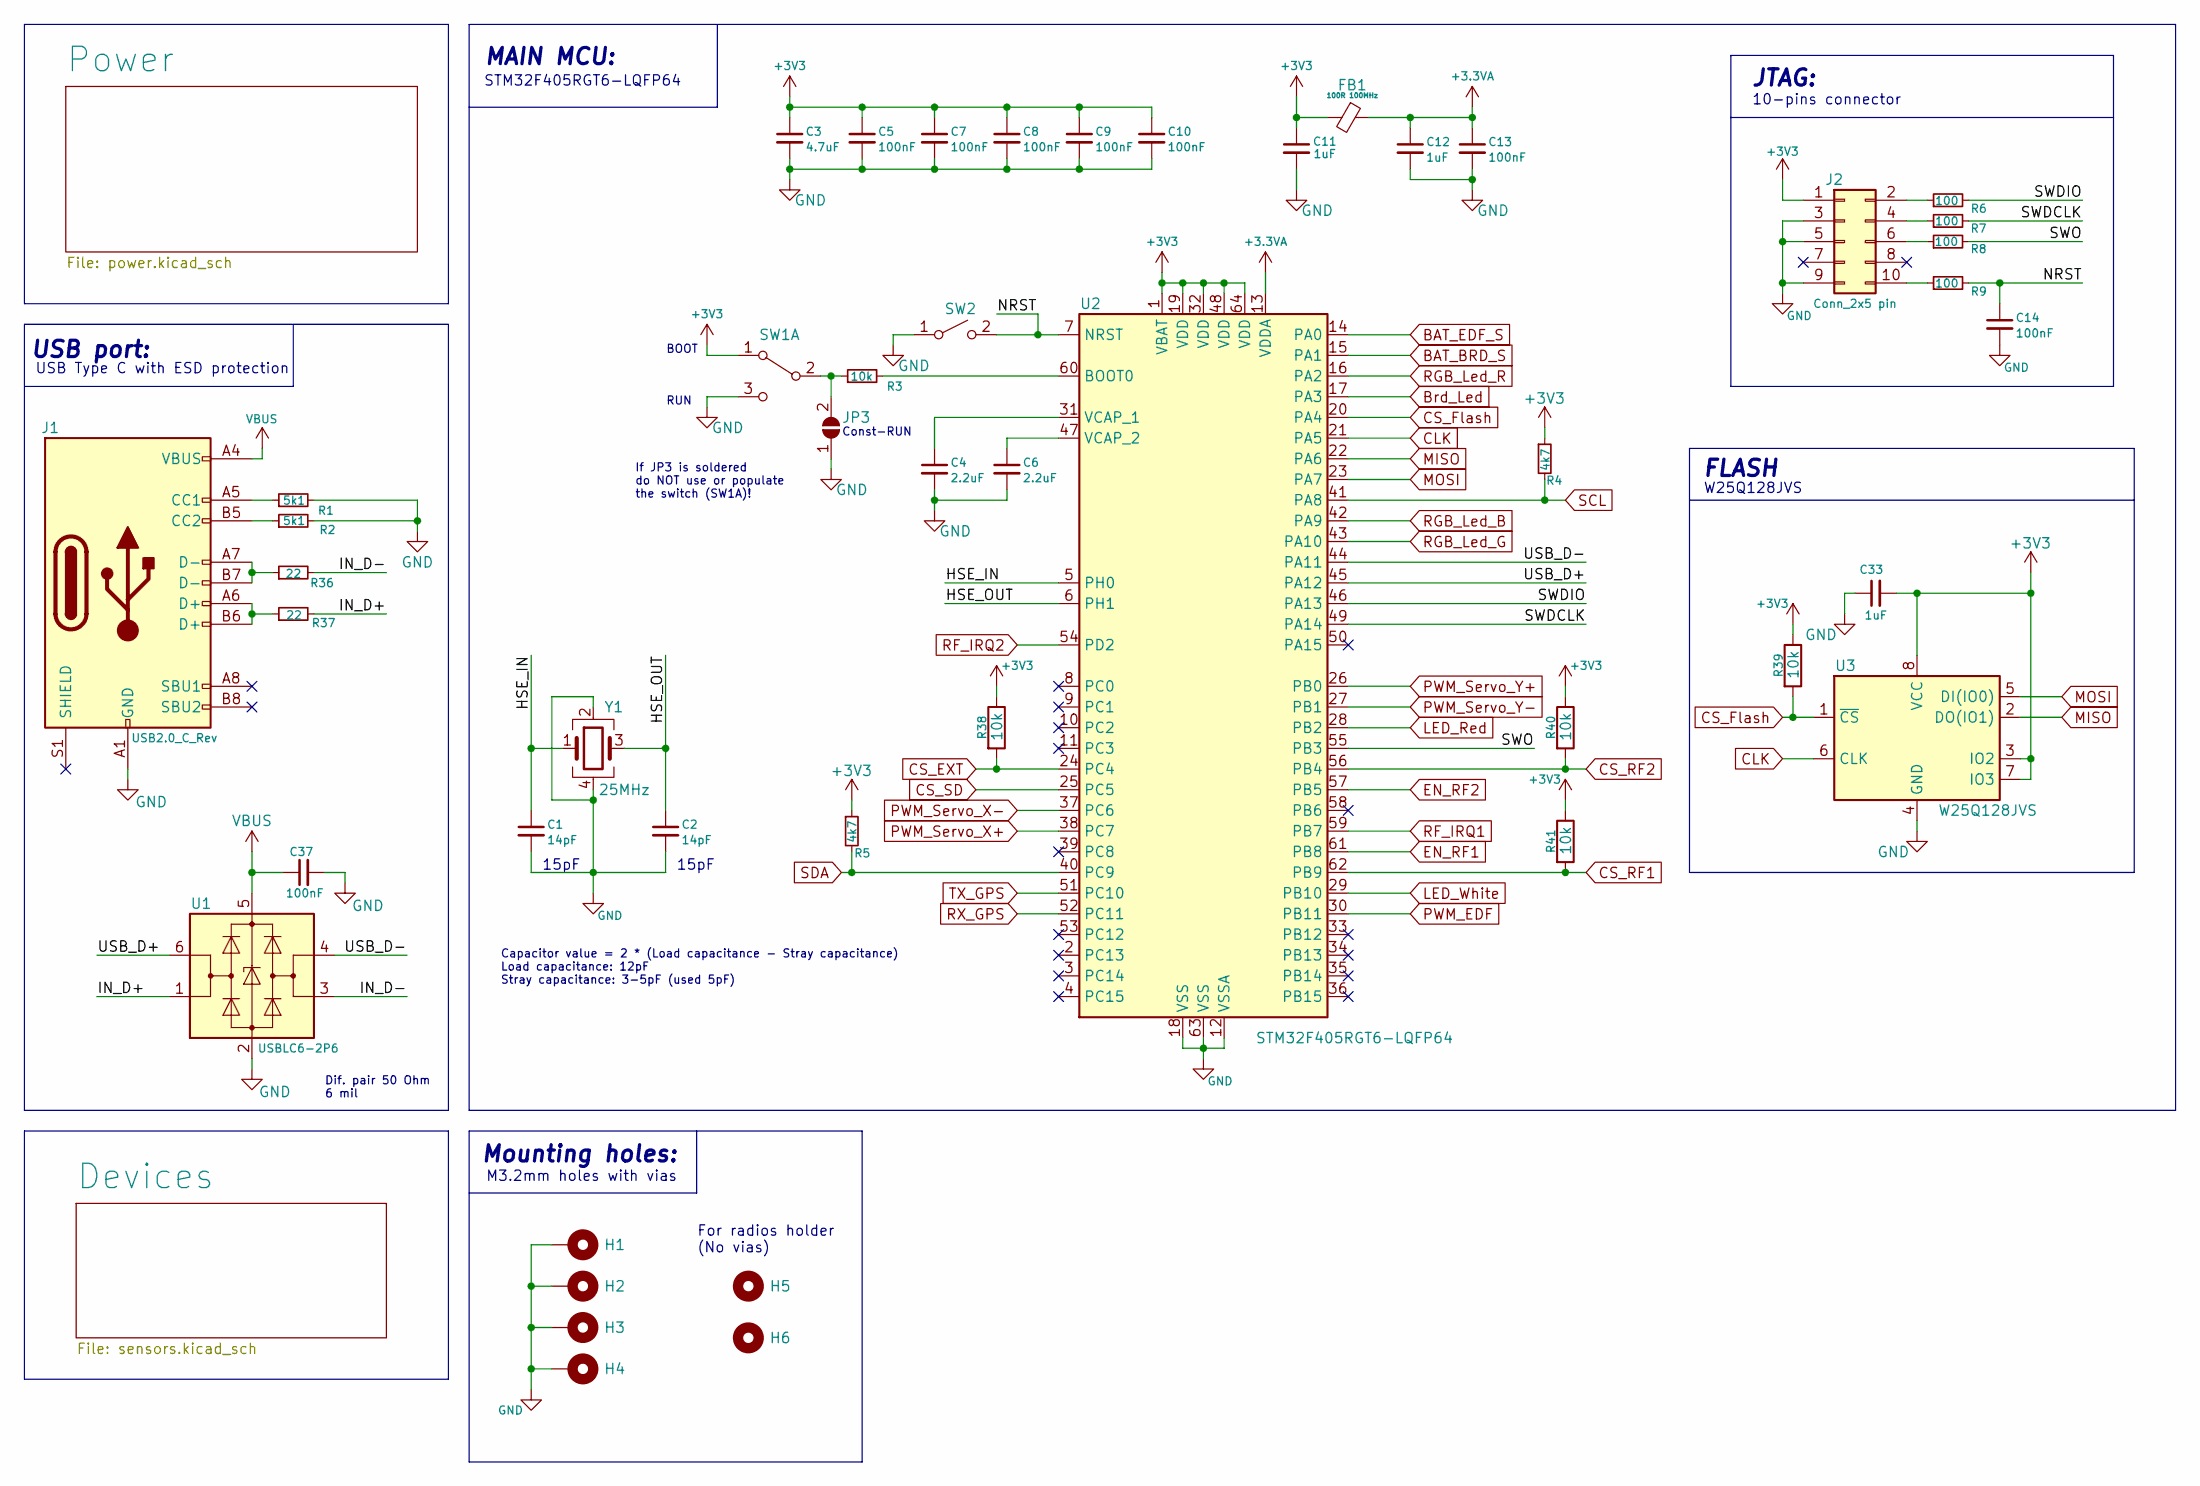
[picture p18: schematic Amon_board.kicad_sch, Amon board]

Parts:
C1, C2: 14pF; C_0603_1608Metric
C3: 4.7uF; C_0603_1608Metric
C4, C6: 2.2uF; C_0603_1608Metric
C5, C7, C8, C9, C10, C13, C14, C37: 100nF; C_0603_1608Metric
C11, C12, C33: 1uF; C_0603_1608Metric
FB1: 100R 100MHz; L_1206_3216Metric_Pad1.22x1.90mm_HandSolder
H1, H2, H3, H4: MountingHole_Pad; MountingHole_3.2mm_M3_Pad_Via
H5, H6: MountingHole; MountingHole_3.2mm_M3
J1: USB2.0_C_Rev; USB_C_Receptacle_XKB_U262-16XN-4BVC11
J2: Conn_2x5 pin; IDC-Header_2x05_P2.54mm_Vertical
JP3: SolderJumper_2_Open; SolderJumper-2_P1.3mm_Open_TrianglePad1.0x1.5mm
R1, R2: 5k1; R_0603_1608Metric
R3, R38, R39, R40, R41: 10k; R_0603_1608Metric
R4, R5: 4k7; R_0603_1608Metric
R6, R7, R8, R9: 100; R_0603_1608Metric
R36, R37: 22; R_0603_1608Metric
SW1: SW_DPDT; SW_SPDT_PCM12
SW2: SW_SPST; SW_Push_1P1T_NO_CK_KMR2
U1: USBLC6-2P6; SOT-23-6_Handsoldering
U2: STM32F405RGT6-LQFP64; LQFP-64_10x10mm_P0.5mm
U3: W25Q128JVS; SOIC-8_5.23x5.23mm_P1.27mm
Y1: 25MHz; Crystal_SMD_3225-4Pin_3.2x2.5mm

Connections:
+3.3VA: C12.1, C13.1, FB1.1, U2.13 (VDDA)
+3V3: C3.1, C5.1, C7.1, C8.1, C9.1, C10.1, C11.1, C33.2, FB1.2, J2.1, R4.1, R5.1, R38.1, R39.1, R40.1, R41.1, SW1.1 (A), U2.1 (VBAT), U2.19 (VDD), U2.32 (VDD), U2.48 (VDD), U2.64 (VDD), U3.3 (IO2), U3.7 (IO3), U3.8 (VCC); also elsewhere on the board
/HSE_IN: C1.1, U2.5 (PH0), Y1.1
/HSE_OUT: C2.1, U2.6 (PH1), Y1.3
/IN_D+: R37.2, U1.1 (I/O1)
/IN_D-: R36.2, U1.3 (I/O2)
/NRST: C14.1, R9.2, SW2.2 (B), U2.7 (NRST)
/SWDCLK: R7.2, U2.49 (PA14)
/SWDIO: R6.2, U2.46 (PA13)
/SWO: R8.2, U2.55 (PB3)
/USB_D+: U1.6 (I/O1), U2.45 (PA12)
/USB_D-: U1.4 (I/O2), U2.44 (PA11)
BAT_BRD_S: U2.15 (PA1); also elsewhere on the board
BAT_EDF_S: U2.14 (PA0); also elsewhere on the board
Brd_Led: U2.17 (PA3); also elsewhere on the board
CLK: U2.21 (PA5), U3.6 (CLK); also elsewhere on the board
CS_EXT: R38.2, U2.24 (PC4); also elsewhere on the board
CS_Flash: R39.2, U2.20 (PA4), U3.1 (~CS)
CS_RF1: R41.2, U2.62 (PB9); also elsewhere on the board
CS_RF2: R40.2, U2.56 (PB4); also elsewhere on the board
CS_SD: U2.25 (PC5); also elsewhere on the board
EN_RF1: U2.61 (PB8); also elsewhere on the board
EN_RF2: U2.57 (PB5); also elsewhere on the board
GND: C1.2, C2.2, C3.2, C4.2, C5.2, C6.2, C7.2, C8.2, C9.2, C10.2, C11.2, C12.2, C13.2, C14.2, C33.1, C37.2, H1.1, H2.1, H3.1, H4.1, J1.A1 (GND), J1.A12 (GND), J1.B1 (GND), J1.B12 (GND), J2.3, J2.5, J2.9, JP3.1 (A), R1.2, R2.2, SW1.3 (C), SW2.1 (A), U1.2 (GND), U2.12 (VSSA), U2.18 (VSS), U2.63 (VSS), U3.4 (GND), Y1.2, Y1.4; also elsewhere on the board
LED_Red: U2.28 (PB2); also elsewhere on the board
LED_White: U2.29 (PB10); also elsewhere on the board
MISO: U2.22 (PA6), U3.2 (DO(IO1)); also elsewhere on the board
MOSI: U2.23 (PA7), U3.5 (DI(IO0)); also elsewhere on the board
unnamed: J1.A5 (CC1), R1.1
unnamed: J1.B5 (CC2), R2.1
unnamed: J1.A6 (D+), J1.B6 (D+), R37.1
unnamed: J1.A7 (D-), J1.B7 (D-), R36.1
unnamed: J2.2, R6.1
unnamed: J2.4, R7.1
unnamed: J2.6, R8.1
unnamed: J2.10, R9.1
unnamed: JP3.2 (B), R3.1, SW1.2 (B)
unnamed: R3.2, U2.60 (BOOT0)
unnamed: C4.1, U2.31 (VCAP_1)
unnamed: C6.1, U2.47 (VCAP_2)
PWM_EDF: U2.30 (PB11); also elsewhere on the board
PWM_Servo_X+: U2.38 (PC7); also elsewhere on the board
PWM_Servo_X-: U2.37 (PC6); also elsewhere on the board
PWM_Servo_Y+: U2.26 (PB0); also elsewhere on the board
PWM_Servo_Y-: U2.27 (PB1); also elsewhere on the board
RF_IRQ1: U2.59 (PB7); also elsewhere on the board
RF_IRQ2: U2.54 (PD2); also elsewhere on the board
RGB_Led_B: U2.42 (PA9); also elsewhere on the board
RGB_Led_G: U2.43 (PA10); also elsewhere on the board
RGB_Led_R: U2.16 (PA2); also elsewhere on the board
RX_GPS: U2.52 (PC11); also elsewhere on the board
SCL: R4.2, U2.41 (PA8); also elsewhere on the board
SDA: R5.2, U2.40 (PC9); also elsewhere on the board
TX_GPS: U2.51 (PC10); also elsewhere on the board
VBUS: C37.1, J1.A4 (VBUS), J1.A9 (VBUS), J1.B4 (VBUS), J1.B9 (VBUS), U1.5 (VBUS)

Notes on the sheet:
15pF
W25Q128JVS
10-pins connector
If JP3 is soldered do NOT use or populate the switch (SW1A)!
Capacitor value = 2 * (Load capacitance - Stray capacitance) Load capacitance: 12pF Stray capacitance: 3-5pF (used 5pF)
RUN
JTAG:
M3.2mm holes with vias
Dif. pair 50 Ohm 6 mil
USB port:
Const-RUN
FLASH
Mounting holes:
MAIN MCU:
USB Type C with ESD protection
BOOT
For radios holder (No vias)
STM32F405RGT6-LQFP64

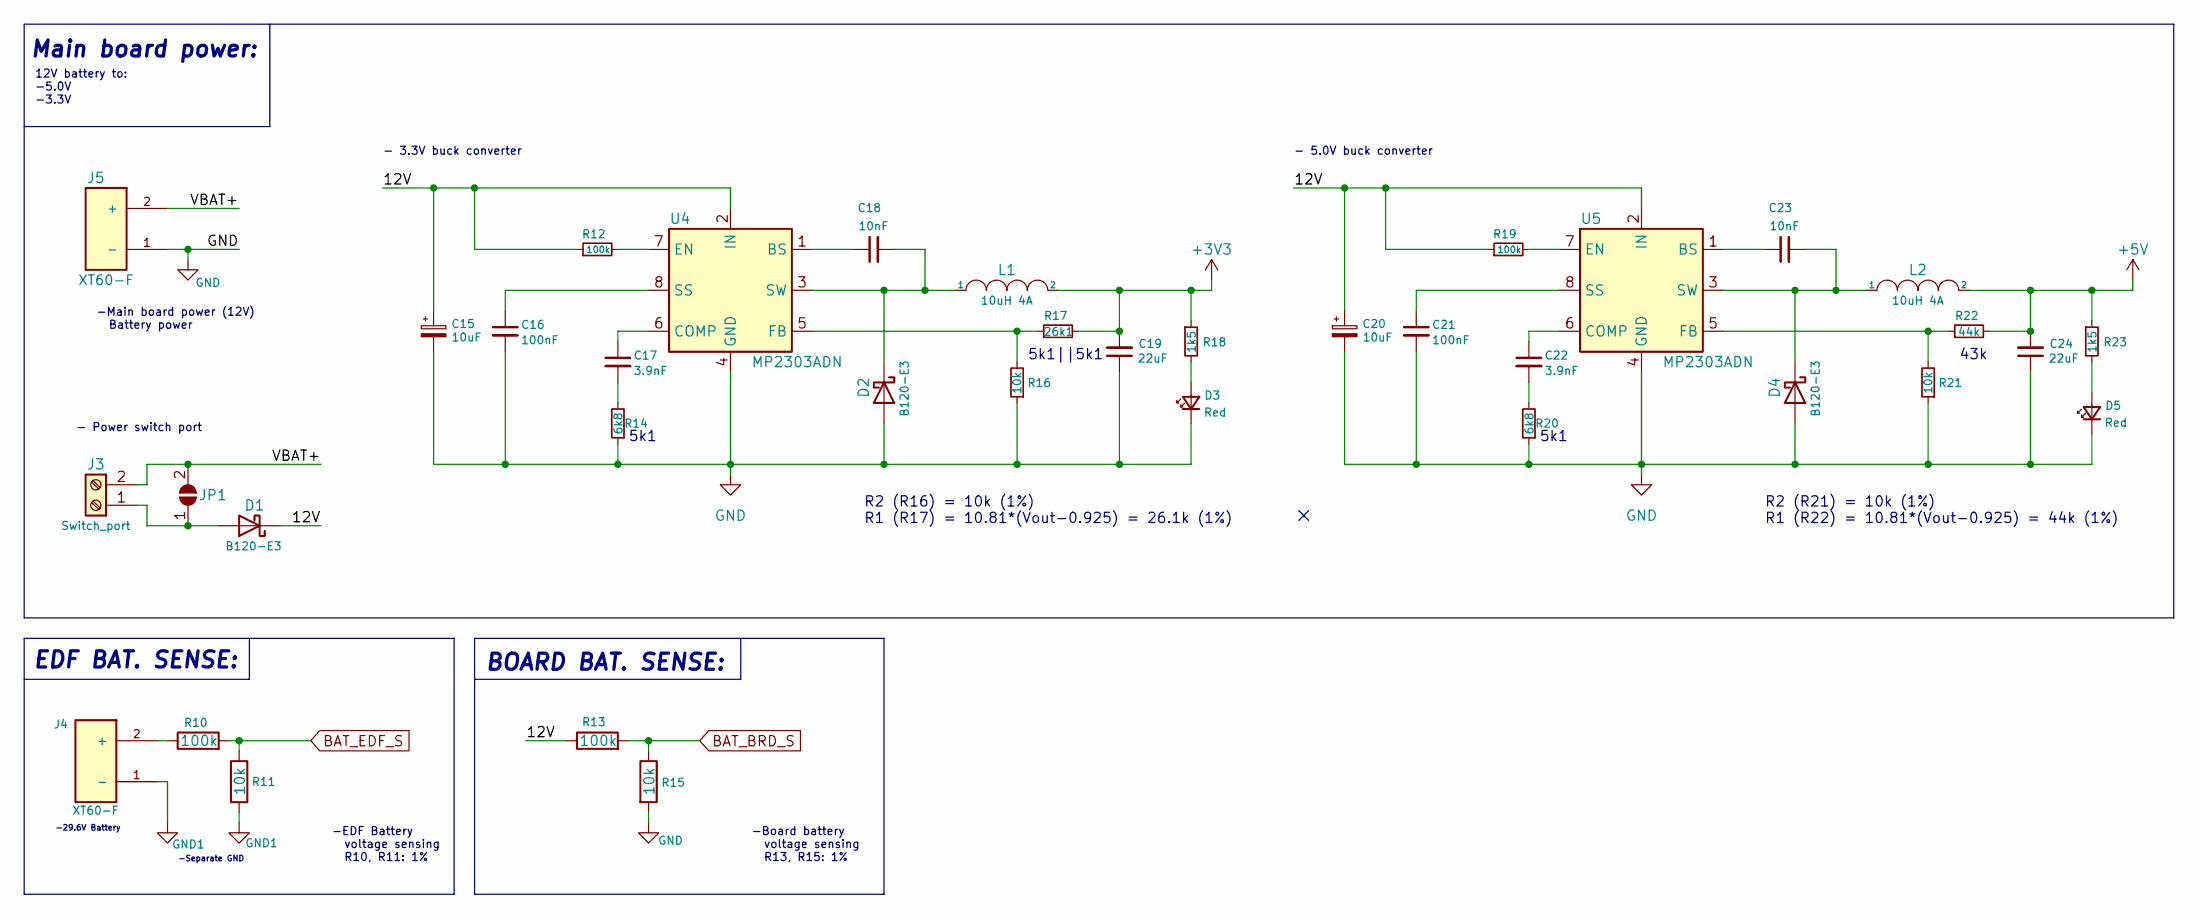
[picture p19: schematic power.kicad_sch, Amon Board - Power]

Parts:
C15, C20: 10uF; CP_EIA-3216-10_Kemet-I
C16, C21: 100nF; C_0603_1608Metric
C17, C22: 3.9nF; C_0603_1608Metric
C18, C23: 10nF; C_0603_1608Metric
C19, C24: 22uF; C_1206_3216Metric
D1, D2, D4: B120-E3; D_SMA
D3, D5: Red; LED_0603_1608Metric
J3: Switch_port; TerminalBlock_MetzConnect_Type055_RT01502HDWU_1x02_P5.00mm_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
J4, J5: XT60-F; AMASS_XT60-M; PARTREV 1.2
JP1: SolderJumper_2_Open; SolderJumper-2_P1.3mm_Open_Pad1.0x1.5mm
L1, L2: 10uH 4A; L_10.4x10.4_H4.8
R10, R13: 100k; R_1206_3216Metric
R11, R15: 10k; R_1206_3216Metric
R12, R19: 100k; R_0603_1608Metric
R14, R20: 6k8; R_0603_1608Metric
R16, R21: 10k; R_0603_1608Metric
R17: 26k1; R_0603_1608Metric
R18, R23: 1k5; R_0603_1608Metric
R22: 44k; R_0603_1608Metric
U4, U5: MP2303ADN; SOIC-8-1EP_3.9x4.9mm_P1.27mm_EP2.62x3.51mm

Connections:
+3V3: C19.2, L1.2, R17.2, R18.1; also elsewhere on the board
+5V: C24.2, L2.2, R22.2, R23.1; also elsewhere on the board
/Power/12V: C15.1, C20.1, D1.1 (K), R12.1, R13.1, R19.1, U4.2 (IN), U5.2 (IN)
/Power/VBAT+: J3.2, J5.2 (+), JP1.2 (B)
BAT_BRD_S: R13.2, R15.1; also elsewhere on the board
BAT_EDF_S: R10.2, R11.1; also elsewhere on the board
GND: C15.2, C16.2, C19.1, C20.2, C21.2, C24.1, D2.2 (A), D3.1 (K), D4.2 (A), D5.1 (K), J5.1 (-), R14.1, R15.2, R16.1, R20.1, R21.1, U4.4 (GND), U5.4 (GND); also elsewhere on the board
GND1: J4.1 (-), R11.2
unnamed: C17.2, R14.2
unnamed: C22.2, R20.2
unnamed: D1.2 (A), J3.1, JP1.1 (A)
unnamed: C18.2, D2.1 (K), L1.1, U4.3 (SW)
unnamed: D3.2 (A), R18.2
unnamed: C23.2, D4.1 (K), L2.1, U5.3 (SW)
unnamed: D5.2 (A), R23.2
unnamed: J4.2 (+), R10.1
unnamed: C18.1, U4.1 (BS)
unnamed: C17.1, U4.6 (COMP)
unnamed: R12.2, U4.7 (EN)
unnamed: R16.2, R17.1, U4.5 (FB)
unnamed: C16.1, U4.8 (SS)
unnamed: C23.1, U5.1 (BS)
unnamed: C22.1, U5.6 (COMP)
unnamed: R19.2, U5.7 (EN)
unnamed: R21.2, R22.1, U5.5 (FB)
unnamed: C21.1, U5.8 (SS)

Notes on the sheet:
-Board battery voltage sensing R13, R15: 1%
5k1||5k1
-Separate GND
-Main board power (12V) Battery power
5k1
- 5.0V buck converter
BOARD BAT. SENSE:
-29.6V Battery
-EDF Battery voltage sensing R10, R11: 1%
12V battery to: -5.0V -3.3V
- 3.3V buck converter
- Power switch port
EDF BAT. SENSE:
R2 (R21) = 10k (1%) R1 (R22) = 10.81*(Vout-0.925) = 44k (1%)
43k
Main board power:
R2 (R16) = 10k (1%) R1 (R17) = 10.81*(Vout-0.925) = 26.1k (1%)

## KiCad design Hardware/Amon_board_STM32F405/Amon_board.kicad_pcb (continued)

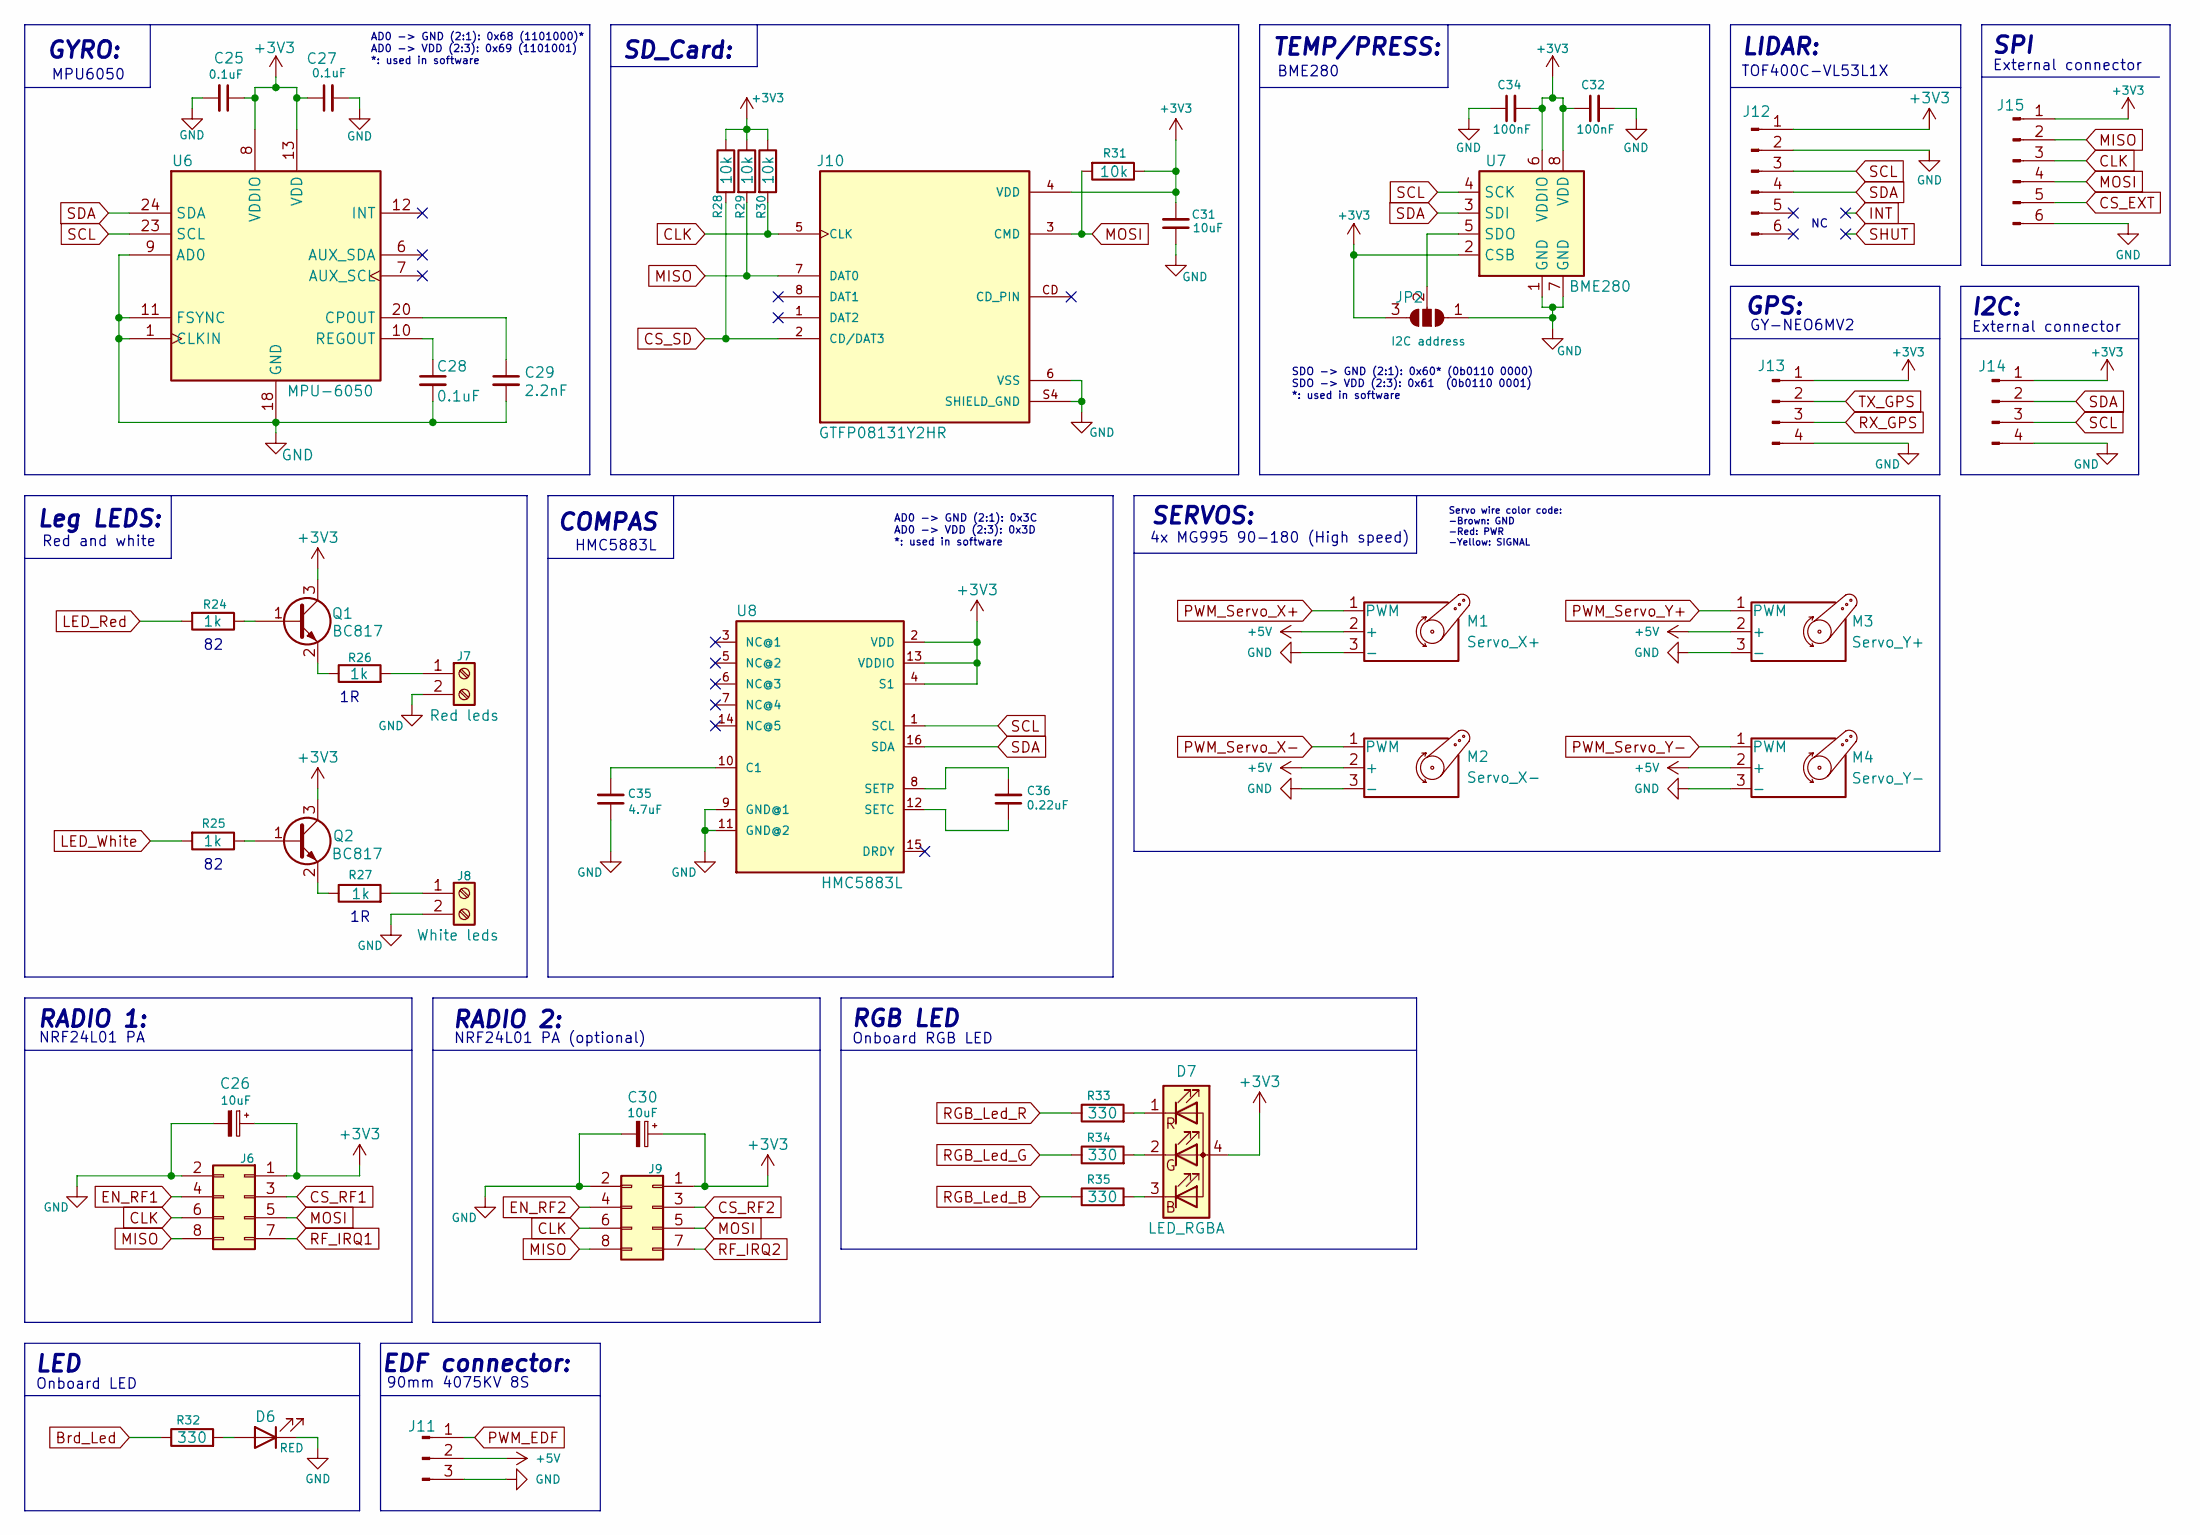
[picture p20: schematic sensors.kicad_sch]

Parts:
C25, C27, C28: 0.1uF; C_0603_1608Metric
C26, C30: 10uF; CP_Elec_4x5.4
C29: 2.2nF; C_0603_1608Metric
C31: 10uF; C_0603_1608Metric
C32, C34: 100nF; C_0603_1608Metric
C35: 4.7uF; C_0603_1608Metric
C36: 0.22uF; C_0603_1608Metric
D6: RED; LED_0603_1608Metric
D7: LED_RGBA; LED_Cree-PLCC4_3.2x2.8mm_CCW
J6, J9: Conn_02x04_Odd_Even; PinSocket_2x04_P2.54mm_Vertical
J7: Red leds; TerminalBlock_MetzConnect_Type055_RT01502HDWU_1x02_P5.00mm_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
J8: White leds; TerminalBlock_MetzConnect_Type055_RT01502HDWU_1x02_P5.00mm_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
J10: GTFP08131Y2HR; AMPHENOL_GTFP08131Y2HR; PARTREV A
J11: Conn_01x03_Male; PinHeader_1x03_P2.54mm_Vertical
J12: Conn_01x06_Male; JST_XH_S6B-XH-A-1_1x06_P2.50mm_Horizontal
J13: Conn_01x04_Male; JST_XH_S4B-XH-A_1x04_P2.50mm_Horizontal
J14: Conn_01x04_Male; PinHeader_1x04_P2.54mm_Vertical
J15: Conn_01x06_Male; PinHeader_1x06_P2.54mm_Vertical
JP2: I2C address; SolderJumper-3_P1.3mm_Open_RoundedPad1.0x1.5mm_NumberLabels
M1: Servo_X+; PinHeader_1x03_P2.54mm_Vertical
M2: Servo_X-; PinHeader_1x03_P2.54mm_Vertical
M3: Servo_Y+; PinHeader_1x03_P2.54mm_Vertical
M4: Servo_Y-; PinHeader_1x03_P2.54mm_Vertical
Q1, Q2: BC817; SOT-23
R24, R25, R26, R27: 1k; R_0603_1608Metric
R28, R29, R30, R31: 10k; R_0603_1608Metric
R32, R33, R34, R35: 330; R_0603_1608Metric
U6: MPU-6050; InvenSense_QFN-24_4x4mm_P0.5mm
U7: BME280; Bosch_LGA-8_2x2.5mm_P0.65mm_ClockwisePinNumbering
U8: HMC5883L; LPCC-16

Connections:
+3V3: C25.1, C26.1, C27.1, C30.1, C31.2, C32.1, C34.2, D7.4 (A), J6.1, J9.1, J10.4 (VDD), J12.1, J13.1, J14.1, J15.1, JP2.3 (B), Q1.3 (C), Q2.3 (C), R28.1, R29.1, R30.1, R31.1, U6.8 (VDDIO), U6.13 (VDD), U7.2 (CSB), U7.6 (VDDIO), U7.8 (VDD), U8.2 (VDD), U8.4 (S1), U8.13 (VDDIO); also elsewhere on the board
+5V: J11.2, M1.2 (+), M2.2 (+), M3.2 (+), M4.2 (+); also elsewhere on the board
Brd_Led: R32.1; also elsewhere on the board
CLK: J6.6, J9.6, J10.5 (CLK), J15.3, R30.2; also elsewhere on the board
CS_EXT: J15.5; also elsewhere on the board
CS_RF1: J6.3; also elsewhere on the board
CS_RF2: J9.3; also elsewhere on the board
CS_SD: J10.2 (CD/DAT3), R28.2; also elsewhere on the board
EN_RF1: J6.4; also elsewhere on the board
EN_RF2: J9.4; also elsewhere on the board
GND: C25.2, C26.2, C27.2, C28.2, C29.2, C30.2, C31.1, C32.2, C34.1, C35.1, D6.1 (K), J6.2, J7.2, J8.2, J9.2, J10.6 (VSS), J10.S4 (SHIELD_GND), J11.3, J12.2, J13.4, J14.4, J15.6, JP2.1 (A), M1.3 (-), M2.3 (-), M3.3 (-), M4.3 (-), U6.1 (CLKIN), U6.9 (AD0), U6.11 (FSYNC), U6.18 (GND), U7.1 (GND), U7.7 (GND), U8.9 (GND@1), U8.11 (GND@2); also elsewhere on the board
LED_Red: R24.2; also elsewhere on the board
LED_White: R25.2; also elsewhere on the board
MISO: J6.8, J9.8, J10.7 (DAT0), J15.2, R29.2; also elsewhere on the board
MOSI: J6.5, J9.5, J10.3 (CMD), J15.4, R31.2; also elsewhere on the board
unnamed: D6.2 (A), R32.2
unnamed: D7.3 (BK), R35.2
unnamed: D7.2 (GK), R34.2
unnamed: D7.1 (RK), R33.2
unnamed: J7.1, R26.2
unnamed: J8.1, R27.2
unnamed: JP2.2 (C), U7.5 (SDO)
unnamed: Q1.1 (B), R24.1
unnamed: Q1.2 (E), R26.1
unnamed: Q2.1 (B), R25.1
unnamed: Q2.2 (E), R27.1
unnamed: C29.1, U6.20 (CPOUT)
unnamed: C28.1, U6.10 (REGOUT)
unnamed: C35.2, U8.10 (C1)
unnamed: C36.1, U8.12 (SETC)
unnamed: C36.2, U8.8 (SETP)
PWM_EDF: J11.1; also elsewhere on the board
PWM_Servo_X+: M1.1 (PWM); also elsewhere on the board
PWM_Servo_X-: M2.1 (PWM); also elsewhere on the board
PWM_Servo_Y+: M3.1 (PWM); also elsewhere on the board
PWM_Servo_Y-: M4.1 (PWM); also elsewhere on the board
RF_IRQ1: J6.7; also elsewhere on the board
RF_IRQ2: J9.7; also elsewhere on the board
RGB_Led_B: R35.1; also elsewhere on the board
RGB_Led_G: R34.1; also elsewhere on the board
RGB_Led_R: R33.1; also elsewhere on the board
RX_GPS: J13.3; also elsewhere on the board
SCL: J12.3, J14.3, U6.23 (SCL), U7.4 (SCK), U8.1 (SCL); also elsewhere on the board
SDA: J12.4, J14.2, U6.24 (SDA), U7.3 (SDI), U8.16 (SDA); also elsewhere on the board
TX_GPS: J13.2; also elsewhere on the board

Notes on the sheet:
COMPAS
Red and white
Leg LEDS:
GYRO:
External connector
90mm 4075KV 8S
SPI
AD0 -> GND (2:1): 0x3C AD0 -> VDD (2:3): 0x3D *: used in software
I2C:
TOF400C-VL53L1X
Onboard RGB LED
GY-NEO6MV2
TEMP/PRESS:
AD0 -> GND (2:1): 0x68 (1101000)* AD0 -> VDD (2:3): 0x69 (1101001) *: used in software
SERVOS:
4x MG995 90-180 (High speed)
NRF24L01 PA
LED
RADIO 1:
LIDAR:
Onboard LED
HMC5883L
RGB LED
SD_Card:
EDF connector:
NRF24L01 PA (optional)
Servo wire color code: -Brown: GND -Red: PWR -Yellow: SIGNAL
GPS:
SDO -> GND (2:1): 0x60* (0b0110 0000) SDO -> VDD (2:3): 0x61 (0b0110 0001) *: used in software
MPU6050
BME280
RADIO 2:

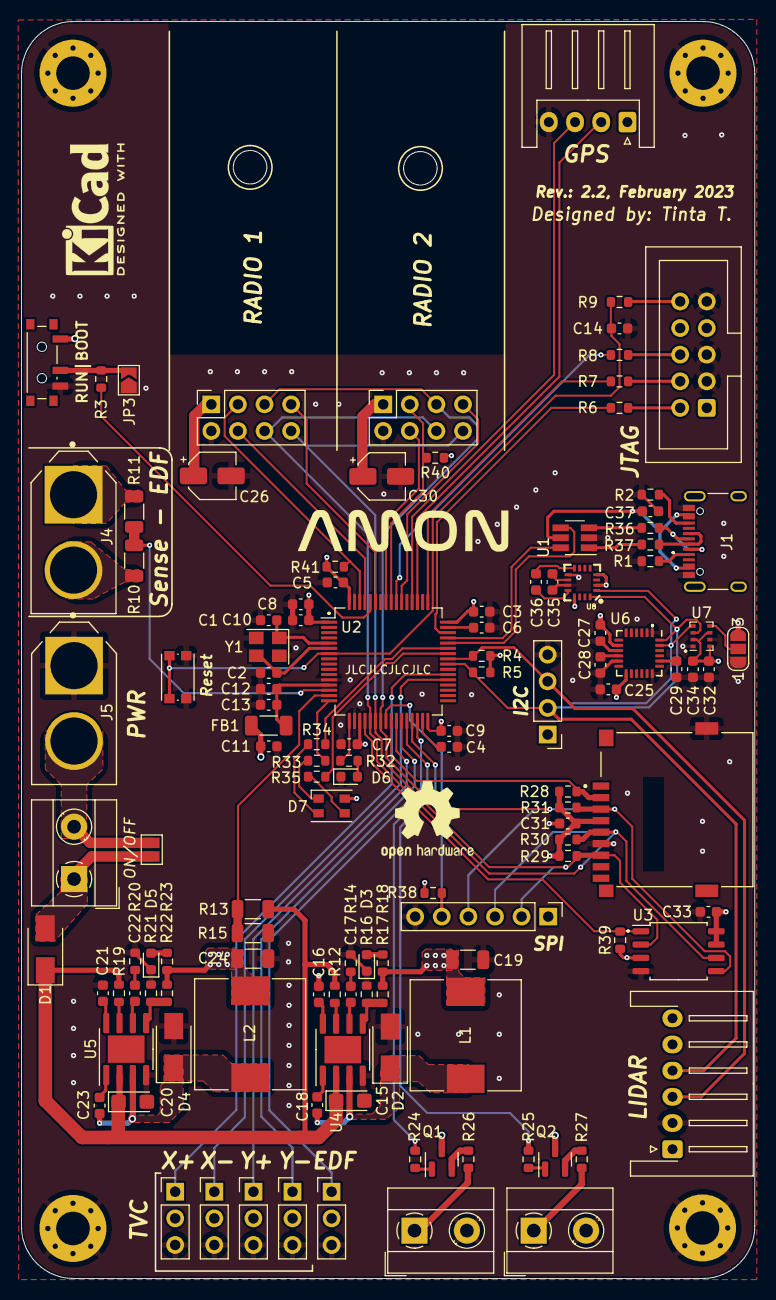
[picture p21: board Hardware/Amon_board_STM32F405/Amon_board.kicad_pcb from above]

Board: 4 copper layers, 70.0 x 120.0 mm, 129 parts (0 on the bottom side), 93 nets.

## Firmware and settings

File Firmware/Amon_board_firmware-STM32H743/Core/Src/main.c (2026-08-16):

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
/* Includes ------------------------------------------------------------------*/
#include "main.h"

/* USER CODE BEGIN PD */
#define RGB_MAX 20000    // PWM max
#define RGB_DIM 4000     // Low brightness
#define RGB_MED 12000    // Medium brightness
#define RGB_BRIGHT 20000 // High brightness
#define STEP    1        // speed of transition

/* USER CODE END PD */

ADC_HandleTypeDef hadc1;
DMA_HandleTypeDef hdma_adc1;

I2C_HandleTypeDef hi2c2;
I2C_HandleTypeDef hi2c4;

SPI_HandleTypeDef hspi2;
SPI_HandleTypeDef hspi3;
SPI_HandleTypeDef hspi4;

TIM_HandleTypeDef htim1;
TIM_HandleTypeDef htim2;
TIM_HandleTypeDef htim3;
TIM_HandleTypeDef htim4;
TIM_HandleTypeDef htim5;
TIM_HandleTypeDef htim6;
TIM_HandleTypeDef htim7;

UART_HandleTypeDef huart5;
UART_HandleTypeDef huart1;
DMA_HandleTypeDef hdma_usart1_rx;

void SystemClock_Config(void);
static void MPU_Config(void);
static void MX_GPIO_Init(void);
static void MX_DMA_Init(void);
static void MX_ADC1_Init(void);
static void MX_SPI4_Init(void);
static void MX_UART5_Init(void);
static void MX_USART1_UART_Init(void);
static void MX_SPI3_Init(void);
static void MX_TIM2_Init(void);
static void MX_I2C2_Init(void);
static void MX_SPI2_Init(void);
static void MX_TIM3_Init(void);
static void MX_TIM4_Init(void);
static void MX_I2C4_Init(void);
static void MX_TIM5_Init(void);
static void MX_TIM6_Init(void);
static void MX_TIM7_Init(void);
static void MX_TIM1_Init(void);
/* USER CODE BEGIN 0 */

/* Functions init */
uint16_t ADC_Read_Main_Battery();
uint16_t ADC_Read_EDF_Battery();
uint16_t ADC_Read_5V_Buck();
uint16_t ADC_Read_7V2_Buck();
uint8_t TVCServoEnable();
uint8_t TVCServoDisable();
void servoTest();
uint8_t EDFEnable();
uint8_t EDFDisable();
uint8_t enable_5v_buck(uint8_t pinState);
uint8_t enable_7v2_buck(uint8_t pinState);
void StatusLED(uint8_t Status);



/* Variables */
volatile uint8_t DroneStatusLocal = 0;
volatile uint8_t DroneStatusOld = 20;
volatile uint8_t StartupInit = 0;
volatile uint8_t armCheck = 0;

uint8_t LED_blink_cnt_ON;
uint8_t LED_blink_cnt_double;
uint8_t LED_blink_cnt_OFF;

volatile uint8_t RF_IRQ1_EN = 0;			// flag to enable irq code
volatile uint8_t RF_IRQ2_EN = 0;			// flag to enable irq code

// Gyroscope calibration
uint8_t  GyroCalibTrig = 0;
uint16_t RGB_Red = 0;
uint16_t RGB_Green = 300;
uint16_t RGB_Blue = 600;
uint16_t RGB_RedMax = 0;
uint16_t RGB_GreenMax = 0;
uint16_t RGB_BlueMax = 0;

uint8_t timer_divider_200to100 = 0;		// Convert 200Hz timer to 100Hz

// Battery data
volatile uint8_t ADC_DMA_DataRdy = 0;
__attribute__((section(".dma_buffer")))
__attribute__((aligned(32)))
volatile uint16_t adc_raw[4];

// GPS data
//uint8_t  USART1_GPSRX_DMA[426] = {"\0"};
__attribute__((section(".dma_buffer")))
__attribute__((aligned(32)))
uint8_t  USART1_GPSRX_DMA[512] = {"\0"};
volatile uint8_t NewGPSData = 0;

// Timers IRQ enable flag
volatile uint8_t IRQ_1HzLoopEN = 0;
volatile uint8_t IRQ_50HzLoopEN = 0;
volatile uint8_t IRQ_200HzLoopEN = 0;
volatile uint8_t IRQ_NMPCLoopEN = 0;



/* STRUCTS */
s_MPU6050 			mpu6050; 		// MPU6050 device driver
s_BME280 			bme280;			// bme280 device driver
VL53L1_DEV 			vl53l1Dev;		// VL53L1 device driver
s_HMC5883L			hmc5883l;		// HMC5883L device driver
s_PMW3901 			pmw3901;		// PMW3901 device driver
//VL53L1X_Version_t vl53l1xVersion_t; // Lidar - unused
//VL53L1X_Result_t vl53l1xResult_t;   // Lidar - unused
s_nRF24L01 			radio1;			// nRF24L01 device driver
s_nRF24L01 			radio2;			// nRF24L01 device driver
s_drone_data 		AmonDrone; 		// All drone data
s_packets 			data_packets;	// Data structure for communication packets
s_adcValues			adc_values;		// Values from ADCs

s_Kalman			kalman_pitch;	// Kalman values for pitch
s_Kalman			kalman_roll;	// Kalman values for roll
s_Kalman			kalman_yaw;		// Kalman values for yaw
s_KalmanZ			kalman_tof;		// Kalman values for height
s_Quaternion		quaternion;		// Quaternion based on Euler angles
s_gyro_correction	gyro_correction;// Gyro correction struct
s_NMPC				nmpc = {0};		// NMPC regulator

/* USER CODE END 0 */

/**
  * @brief  The application entry point.
  * @retval int
  */
int main(void)
{

  /* MPU Configuration--------------------------------------------------------*/
  MPU_Config();

  /* Enable the CPU Cache */

  /* Enable I-Cache---------------------------------------------------------*/
  SCB_EnableICache();

  /* Enable D-Cache---------------------------------------------------------*/
  SCB_EnableDCache();

  /* MCU Configuration--------------------------------------------------------*/

  /* Reset of all peripherals, Initializes the Flash interface and the Systick. */
  HAL_Init();

  /* Configure the system clock */
  SystemClock_Config();

  /* Initialize all configured peripherals */
  MX_GPIO_Init();
  MX_DMA_Init();
  MX_ADC1_Init();
  MX_SPI4_Init();
  MX_UART5_Init();
  MX_USART1_UART_Init();
  MX_SPI3_Init();
  MX_TIM2_Init();
  MX_I2C2_Init();
  MX_SPI2_Init();
  MX_TIM3_Init();
  MX_TIM4_Init();
  MX_I2C4_Init();
  MX_TIM5_Init();
  MX_TIM6_Init();
  MX_TIM7_Init();
  MX_TIM1_Init();
  /* USER CODE BEGIN 2 */

  	// ##### Init ##### //
	AmonDrone.DroneStatus = STATUS_STARTUP;
	AmonDrone.flight_status = STATUS_FLIGHT_GROUND;


	// ##### RADIO CONFIGS ##### //
	// Radio 1 configurations (application specific)
	static const s_nrf_config radio_tx_normal_cfg = {
		.channel = 100,	//42
		.addr_width = AW_5BYTE,
	#ifdef RADIO_HW_ACK
		.auto_ack = 1,
	#else
		.auto_ack = 0,
	#endif
		.dynamic_payload = 1,
		.retries = 15,
		.retry_delay = ARD_3500us, //ARD_1250us
		.datarate = NRF_DATARATE_1MBPS,
		.power = NRF_POWER_0DBM,
	};

    static const s_nrf_config radio_tx_stream_cfg = {
        .channel = 100,	//42
        .addr_width = AW_5BYTE,
        .auto_ack = 0,
        .dynamic_payload = 1,
        .retries = 15,
        .retry_delay = ARD_1250us, //ARD_1250us
        .datarate = NRF_DATARATE_1MBPS,
        .power = NRF_POWER_0DBM,
    };

    static const s_pipe_addr radio_tx_addr = {
        //.tx_addr = { 0xE7, 0xE7, 0xE7, 0xE7, 0xEE } //E8
        .tx_addr = { 0xC2, 0xA1, 0x55, 0x12, 0x01 }
    };

    // Radio 1 configurations (application specific)
    static const s_nrf_config radio_rx_normal_cfg = {
        .channel = 70,
        .addr_width = AW_5BYTE,
	#ifdef RADIO_HW_ACK
        .auto_ack = 1,
	#else
		.auto_ack = 0,
	#endif
		.dynamic_payload = 1,
        .retries = 0,
        .retry_delay = 0,
        .datarate = NRF_DATARATE_1MBPS,
        .power = NRF_POWER_MINUS_6DBM,
    };

    static const s_nrf_config radio_rx_stream_cfg = {
        .channel = 70,
        .addr_width = AW_5BYTE,
        .auto_ack = 0,
        .dynamic_payload = 1,
        .retries = 0,
        .retry_delay = 0,
        .datarate = NRF_DATARATE_1MBPS,
        .power = NRF_POWER_MINUS_6DBM,
    };

    static const s_pipe_addr radio_rx_addr = {
        //.pipe0_rx_addr = { 0xE7, 0xE7, 0xE7, 0xE7, 0xE7 }
        .pipe0_rx_addr = { 0xD4, 0xB2, 0xAA, 0x78, 0x50 }
    };


  /* USER CODE END 2 */

  /* Infinite loop */
  /* USER CODE BEGIN WHILE */
  while (1)
  {
	  /*##### Changing drone status #####*/
	  #ifndef CALIBRATION
	  if (AmonDrone.DroneStatus != DroneStatusOld)
	  {
		  DroneStatusOld = AmonDrone.DroneStatus;
		  DroneStatusLocal = AmonDrone.DroneStatus;
		  StatusLED(AmonDrone.DroneStatus);
	  }
	  #endif

	  	  /*##### RGB cycling when calibrating #####*/
	  #ifdef CALIBRATION
		  AmonDrone.DroneStatus = STATUS_CALIB;
		  DroneStatusLocal = AmonDrone.DroneStatus;
	  #endif




	  /*#############################################################################################################################################
	  #################################################################### RADIO ####################################################################
	  #############################################################################################################################################*/

	  	  /*##### RADIO IRQ HANDLING #####*/
	  	  if (radio1.irq_flag == 1)
	  	  {
			  radio1.irq_flag = 0;

	  		  // TX
	  		  NRF24_HandleIRQ(&radio1);
	  		  radio1.buffers.pipe_data = radio1.irq_on_pipe;
	  		  radio1.irq_on_pipe = 0xFF;
	  		  if (radio1.role == NRF_ROLE_PRX) AmonDrone.radio_data.connection_timeout = 0;	// Reset timeout timer
	  	  }

	  	  if (radio2.irq_flag == 1)
	  	  {
			  radio2.irq_flag = 0;
			  HAL_GPIO_WritePin(LED_BRD_GPIO_Port, LED_BRD_Pin, GPIO_PIN_SET);

	  		  // RX
	  		  NRF24_HandleIRQ(&radio2);
	  		  radio2.buffers.pipe_data = radio2.irq_on_pipe;
	  		  radio2.irq_on_pipe = 0xFF;
	  		  if (radio2.role == NRF_ROLE_PRX) AmonDrone.radio_data.connection_timeout = 0;	// Reset timeout timer
	  	  }

	  	  // Radio watchdog
	  	  NRF24_PollWatchdog(&radio1);
	  	  NRF24_PollWatchdog(&radio2);

	  	  /*##### RADIO - transmit report #####*/
	  	  if (radio1.buffers.flag_tx_done)
	  	  {
	  		  // success
	  		  AmonDrone.radio_data.packet_tx_cnt++;
	  		  radio1.buffers.flag_tx_done = 0;
	  	  }

	  	  if (radio1.buffers.flag_max_rxs_reached)
	  	  {
	  		  // fail
	  		  AmonDrone.radio_data.packet_fail_cnt++;
	  		  radio1.buffers.flag_max_rxs_reached = 0;

	  		  // connection lost detection
	  //		  if (AmonDrone.radio_data.packet_fail_cnt >= 5)
	  //		  {
	  //			  AmonDrone.radio_data.flag_connection_lost = 1;
	  //			  AmonDrone.radio_data.packet_fail_cnt = 0;
	  //			  AmonDrone.radio_data.conn_status = CONN_STATUS_DISCONNECTED;
	  //		  }
	  	  }


	  	  /*##### RADIO - Data received -> read #####*/
	  	  if (radio2.buffers.flag_new_rx)
	  	  {
	  		  NRF24_ReadRXPayload(&radio2);
	  		  AmonDrone.radio_data.flag_new_rf_rx_data = 1;
	  	  }

	  	  /*##### RADIO - Decode, encode, send #####*/
	  	  if (AmonDrone.DroneStatus != STATUS_STARTUP || AmonDrone.DroneStatus != STATUS_ERROR) // &&
	  	  {
	  		  // RX packets
	  		  if (AmonDrone.radio_data.flag_new_rf_rx_data == 1)
	  		  {
	  			  AmonDrone.radio_data.flag_new_rf_rx_data = 0;
	  			  uint8_t ret = RF_decode(radio2.buffers.RX_FIFO, &data_packets, NULL);

	  			  if (ret == TRANSCODE_OK || ret == TRANSCODE_BROADCAST)
	  			  {
	  				  RF_packet_decode(&data_packets, &AmonDrone);
	  			  }

	  			  // ACK required - better link connection
	  			  if (AmonDrone.radio_data.flag_stream_data == 1)
	  			  {
	  				  AmonDrone.radio_data.flag_stream_data = 0;
					#ifdef RADIO_HW_ACK
	  				  radio1.config = &radio_tx_normal_cfg;
	  				  NRF24_init(&radio1);
	  				  HAL_Delay(10);
					#endif
	  			  }
	  		  }


	  		  // TX packets - received and requires ACK
	  		  if (AmonDrone.radio_data.flag_new_rf_tx_data == 1)
	  		  {
	  			  AmonDrone.radio_data.flag_new_rf_tx_data = 0;
	  			  memset(radio1.buffers.TX_FIFO, 0, sizeof(radio1.buffers.TX_FIFO));
	  			  RF_encode(&data_packets, radio1.buffers.TX_FIFO, &radio1.buffers.tx_lenght);
	  			  NRF24_Send(&radio1);
	  		  }
	  	  }


	  	  /*##### RADIO - Send telemetry data or not #####*/
	  	  switch(AmonDrone.radio_data.conn_status) {

	  		// STATE: Drone is NOT connected with ground station
	  		case CONN_STATUS_DISCONNECTED:

	  			// ACK required - better link connection
	  			if (AmonDrone.radio_data.flag_stream_data == 1)
	  			{
	  				AmonDrone.radio_data.flag_stream_data = 0;
				#ifdef RADIO_HW_ACK
	  				radio1.config = &radio_tx_normal_cfg;
	  				NRF24_init(&radio1);
	  				HAL_Delay(2);
				#endif
	  			}

	  			// Detect successful connection
	  			if (AmonDrone.radio_data.flag_connection_begin == 1)
	  			{
	  				AmonDrone.radio_data.conn_status = CONN_STATUS_CONNECTED;
	  			}

	  			break;


	  		// STATE: Drone IS connected with ground station
	  		case CONN_STATUS_CONNECTED:

	  			// TX packets - telemetry send / stream
	  			if (AmonDrone.radio_data.flag_telemetry_send == 1 && AmonDrone.radio_data.flag_new_rf_tx_data == 0)
	  			{
	  				AmonDrone.radio_data.flag_telemetry_send = 0;
	  				packet_create_telemetry(&data_packets, &AmonDrone);
	  				memset(radio1.buffers.TX_FIFO, 0, sizeof(radio1.buffers.TX_FIFO));
	  				RF_encode(&data_packets, radio1.buffers.TX_FIFO, &radio1.buffers.tx_lenght);
	  				//radio1.flag_tx_in_progress = 0;
	  				NRF24_Send(&radio1);
	  				HAL_GPIO_TogglePin(LED_BRD_GPIO_Port, LED_BRD_Pin);
	  			}

	  			break;


	  		// STATE: Default state
	  		default:
	  			// Default
	  			break;
	  		}



	  /*##############################################################################################################################################
	  ##################################################################### UART #####################################################################
	  ##############################################################################################################################################*/

	  	  /* USB TX - TRANSMITING HANDLING */
	  	  if (AmonDrone.uart_buffer.flag_new_uart_tx_data == 1)
	  	  {
	  		  AmonDrone.uart_buffer.flag_new_uart_tx_data = 0;
	  		  packet_create_uart_data(&data_packets, &AmonDrone);
	  		  UART_encode(&data_packets, AmonDrone.uart_buffer.buffer_UART_TX);
	  		  HAL_UART_Transmit(&huart5, (uint8_t*)AmonDrone.uart_buffer.buffer_UART_TX, AmonDrone.uart_buffer.buffer_UART_TX[1] + 2, HAL_MAX_DELAY);
	  		  memset(AmonDrone.uart_buffer.buffer_UART_TX, 0, sizeof(AmonDrone.uart_buffer.buffer_UART_TX));
	  	  }

	  	  /* USB RX - TRANSCODING HANDLING */
	  	  if (AmonDrone.uart_buffer.flag_new_uart_rx_data == 1)
	  	  {
	  		  AmonDrone.uart_buffer.flag_new_uart_rx_data = 0;

	  		  uint8_t ret = UART_decode(AmonDrone.uart_buffer.buffer_UART_RX, &data_packets, &AmonDrone.uart_buffer.flag_new_uart_tx_data, &data_packets.calib_data);
	  		  memset(AmonDrone.uart_buffer.buffer_UART_RX, 0, sizeof(AmonDrone.uart_buffer.buffer_UART_RX));

	  		  // Based on return values trigger events
	  		  switch (ret)
	  		  {
	  			  case TRANSCODE_BOOT_PKT:
	  				  // Unused
	  				  break;

	  			  case TRANSCODE_BROADCAST:
	  				  // Unused
	  				  break;

	  			  case TRANSCODE_VER_ERR:                 	// Wrong version of packet
	  				  break;

	  			  case TRANSCODE_DEST_ERR:                	// Wrong destination address
	  				  break;

	  			  case TRANSCODE_CRC_ERR:                	// Corupted frame / CRC
	  				  break;

	  			  case TRANSCODE_DEST_RF:                 	// Packet for RF transmit
	  				  // Unused
	  				  break;

	  			  case TRANSCODE_DEST_LINK:               	// Packet for link device
	  				  // Unused
	  				  break;

	  			  case TRANSCODE_LOG_DUMP:					// Serial request for flight log dump
	  			  	  //AmonDrone.uart_buffer.flag_log_dump = 1;
	  				  (void)log_dump_uart(AmonDrone.uart_buffer.log_file, &huart5); // "log.txt"
	  			  	  break;

	  			  case TRANSCODE_LOG_RM:					// Serial request for flight log remove
	  				  //AmonDrone.uart_buffer.flag_log_remove = 1;
	  				  log_remove();
	  				  break;

	  			  case TRANSCODE_EN_IDENTI:					// Enable identification flag
	  				  AmonDrone.identifications.flag_test_identification = 1;
	  				  break;

	  			  case TRANSCODE_IDENTI_EDF:				// Enable edf identification flag
	  				  AmonDrone.identifications.flag_test_edf = 1;
	  				  break;

	  			  case TRANSCODE_IDENTI_SERVO:				// Enable servo identification flag
	  				  AmonDrone.identifications.flag_test_servo = 1;
	  				  break;

	  			  case TRANSCODE_IDENTI_MOMENT:				// Enable moment identification flag
	  				  AmonDrone.identifications.flag_test_moment = 1;
	  				  break;

	  			  case TRANSCODE_CAL_COMM:					// Serial calibration commands
	  				  // Full packet required (all fields must have value)
					#ifdef IDENTIFICATION
	  				  // Identification test - EDF and Servos - UART RX
	  				  if (AmonDrone.actuators.edf_enable == 0) EDFEnable();
	  				  PowerToPWMValue(data_packets.calib_data.edf_pwr_percent);
	  				  AmonDrone.actuators.edf_percent = data_packets.calib_data.edf_pwr_percent;

	  				  if (AmonDrone.actuators.servo_enable == 0)
					  {
						enable_7v2_buck(ENABLE);
						TVCServoEnable();
					  } 
	  				  DegresToCCR(data_packets.calib_data.x_plus_angle, SERVO_XP);
	  				  DegresToCCR(data_packets.calib_data.x_minus_angle, SERVO_XN);
	  				  DegresToCCR(data_packets.calib_data.y_plus_angle, SERVO_YP);
	  				  DegresToCCR(data_packets.calib_data.y_minus_angle, SERVO_YN);
					#endif
	  				  break;

	  			  default:                                	// Default state
	  				  break;
	  		  }
	  	  }



	  /*##############################################################################################################################################
	  #################################################################### TIMERS ####################################################################
	  ##############################################################################################################################################*/


	  	  /*##### TIMERS - Timer flag triggers #####*/
	  	  if (AmonDrone.DroneStatus != STATUS_STARTUP ) // && AmonDrone.DroneStatus != STATUS_ERROR
	  	  {
	  		  // --- Timer 6 - 200Hz / 5ms ---
	  		  if (IRQ_200HzLoopEN == 1)
	  		  {
	  			  IRQ_200HzLoopEN = 0;

	  			  timer_divider_200to100++;

	  			  // --- Timer divider: 200Hz to 100Mz ---
				  if (timer_divider_200to100 >= 2)
				  {
					  // TODO: Check if solver blocks some cycles of filter
					  timer_divider_200to100 = 0;

					// IDENTIFICATION TEST - LOCAL //
					#if defined(IDENTIFICATION) && defined(TEST_SEQUENCE)
						if (Identification_RunTest(&AmonDrone))
						{
							if (AmonDrone.actuators.edf_enable == 0) EDFEnable();
							if (AmonDrone.actuators.servo_enable == 0)
							{
								enable_7v2_buck(ENABLE);
								TVCServoEnable();
							}
						}
					#endif

					  // Kalman filter for height - ToF //
					  float accel_z_world = AccelBodyToWorldZ(AmonDrone.position.accel_x, AmonDrone.position.accel_y, AmonDrone.position.accel_z, AmonDrone.position.quaternion);

					  if (!isfinite(accel_z_world))
					  {
						  accel_z_world = kalman_tof.accel_z_world_bias;
					  }

					  // Estimate vertical accelerometer bias only while the vehicle is not flying
					  if (AmonDrone.DroneStatus != STATUS_FLY)
					  {
						  const float bias_alpha = TIM_100HZ_DT / (AZ_BIAS_LPF_TAU_S + TIM_100HZ_DT);
						  kalman_tof.accel_z_world_bias += bias_alpha * (accel_z_world - kalman_tof.accel_z_world_bias);
						  kalman_tof.accel_z_world_filtered = kalman_tof.accel_z_world_bias;
					  }
					  else
					  {
						  float accel_error = accel_z_world - kalman_tof.accel_z_world_bias;

						  if (accel_error > AZ_PREDICT_LIMIT_M_S2)
						  {
							  accel_z_world = kalman_tof.accel_z_world_bias + AZ_PREDICT_LIMIT_M_S2;
						  }
						  else if (accel_error < -AZ_PREDICT_LIMIT_M_S2)
						  {
							  accel_z_world = kalman_tof.accel_z_world_bias - AZ_PREDICT_LIMIT_M_S2;
						  }

						  kalman_tof.accel_z_world_filtered = LowPassFilter_Accel(accel_z_world, kalman_tof.accel_z_world_filtered, TIM_100HZ_DT);
					  }

					  KalmanZ_Predict(&kalman_tof, kalman_tof.accel_z_world_filtered, TIM_100HZ_DT);

					  if (AmonDrone.position.flag_new_ToF_data)
					  {
						  float z_meas = AmonDrone.position.height_TOF_mm / 1000.0f; // [m]
						  KalmanZ_ProcessToFMeasurement(&kalman_tof, z_meas);
						  AmonDrone.position.flag_new_ToF_data = 0;
					  }
					  
					  AmonDrone.position.height_TOF_m_filtered = kalman_tof.z;    // position z [m]

					  // Smooth only the vertical velocity; keep the height estimate undelayed.
					  AmonDrone.position.velocity_z = LowPassFilter_Update(kalman_tof.vz, AmonDrone.position.velocity_z, TIM_100HZ_DT); // filtered vz [m/s]	

				  } // Timer divider: 200Hz to 100Mz



				  // Enable data transition over UART for identification - test za fft gyrota
					#ifndef TEST_SEQUENCE
						if (AmonDrone.identifications.flag_test_moment) AmonDrone.uart_buffer.flag_new_uart_tx_data = 1;
						if (AmonDrone.identifications.flag_test_edf) AmonDrone.uart_buffer.flag_new_uart_tx_data = 1;
					#endif


	  			  // Read sensors //
	  			  MPU6050_ReadAllDirect(&mpu6050, &hi2c2);

	  			  /* Axis mapping: Sensor -> Drone frame
				   * Drone X+ = Right
				   * Drone Y+ = Forward
				   * Drone Z+ = Up
				   *
				   * body X =  sensor Y
				   * body Y = -sensor Z
				   * body Z =  sensor X
				   */
	  			  AmonDrone.position.gyroTemp = (uint16_t)mpu6050.Temp_C;

				  AmonDrone.position.accel_x =  mpu6050.ACCEL_Y;
				  AmonDrone.position.accel_y = -mpu6050.ACCEL_Z;
				  AmonDrone.position.accel_z =  mpu6050.ACCEL_X;

				  AmonDrone.position.gyro_x  = -(mpu6050.GYRO_Y - AmonDrone.position.gyro_bias_y);
				  AmonDrone.position.gyro_y  = -(mpu6050.GYRO_Z - AmonDrone.position.gyro_bias_z);
				  AmonDrone.position.gyro_z  =  (mpu6050.GYRO_X - AmonDrone.position.gyro_bias_x);

				  AmonDrone.position.Pitch_rate = AmonDrone.position.gyro_x * DEG_TO_RAD;
				  AmonDrone.position.Roll_rate  = AmonDrone.position.gyro_y * DEG_TO_RAD;
				  AmonDrone.position.Yaw_rate   = AmonDrone.position.gyro_z * DEG_TO_RAD;

	  			  // Gyro filters //
				#ifndef GYRO_KALMAN
	  			  // Complementary filter
	  			  Complementary_deg(&mpu6050, &AmonDrone); // calculate data to pitch and roll (and yaw)
				#else
	  			  // Kalman Filter - angles and axis described in filters.h
	  			  float roll_angle_accel  = 0;
	  			  float pitch_angle_accel = 0;

	  			  Kalman_rawToAngles(&AmonDrone, &roll_angle_accel, &pitch_angle_accel);
				  roll_angle_accel  = unwrap_to_ref(roll_angle_accel,  kalman_roll.angle);
				  pitch_angle_accel = unwrap_to_ref(pitch_angle_accel, kalman_pitch.angle);

				  AmonDrone.position.Pitch = Kalman_Update(&kalman_pitch, AmonDrone.position.gyro_x, pitch_angle_accel, DT);
	  			  AmonDrone.position.Roll = Kalman_Update(&kalman_roll, AmonDrone.position.gyro_y, roll_angle_accel, DT);
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

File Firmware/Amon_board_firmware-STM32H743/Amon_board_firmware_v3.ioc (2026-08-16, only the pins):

Mcu.UserName=STM32H743VITx
PA0.GPIO_Label=SERVO_XP
PA0.Signal=S_TIM2_CH1_ETR
PA1.GPIO_Label=SERVO_XN
PA1.Signal=S_TIM2_CH2
PA12.GPIO_Label=RF1_IRQ
PA12.Signal=GPXTI12
PA2.GPIO_Label=SERVO_YP
PA2.Signal=S_TIM2_CH3
PA3.GPIO_Label=SERVO_YN
PA3.Signal=S_TIM2_CH4
PA4.GPIO_Label=ADC1_18_BUCK_5V
PA4.Signal=ADCx_INP18
PA5.GPIO_Label=EN_BUCK_5V
PA5.Signal=GPIO_Output
PA6.GPIO_Label=ADC1_3_BUCK_7V2
PA6.Signal=ADCx_INP3
PA7.GPIO_Label=EN_BUCK_7V2
PA7.Signal=GPIO_Output
PA9.Signal=SPI2_SCK
PB0.GPIO_Label=AUX_PORT
PB0.Signal=GPIO_Output
PB1.GPIO_Label=EDF
PB1.Signal=S_TIM3_CH4
PB10.GPIO_Label=I2C_SCL_S
PB10.Signal=I2C2_SCL
PB11.GPIO_Label=I2C_SDA_S
PB11.Signal=I2C2_SDA
PB12.GPIO_Label=UART5_RX_USB
PB12.Signal=UART5_RX
PB13.GPIO_Label=UART5_TX_USB
PB13.Signal=UART5_TX
PB14.GPIO_Label=UART1_TX_GPS
PB14.Signal=USART1_TX
PB15.GPIO_Label=UART1_RX_GPS
PB15.Signal=USART1_RX
PB6.GPIO_Label=RGB_R
PB6.Signal=S_TIM4_CH1
PB7.GPIO_Label=RGB_G
PB7.Signal=S_TIM4_CH2
PB8.GPIO_Label=RGB_B
PB8.Signal=S_TIM4_CH3
PB9.GPIO_Label=LED_BRD
PB9.Signal=GPIO_Output
PC0.GPIO_Label=ADC1_10_EDF
PC0.Signal=ADCx_INP10
PC1.GPIO_Label=ADC1_11_MAIN
PC1.Signal=ADCx_INP11
PC10.GPIO_Label=SPI3_SCK_RF
PC10.Signal=SPI3_SCK
PC11.GPIO_Label=SPI3_MISO_RF
PC11.Signal=SPI3_MISO
PC12.GPIO_Label=SPI3_MOSI_RF
PC12.Signal=SPI3_MOSI
PC2_C.Signal=SPI2_MISO
PC3_C.Signal=SPI2_MOSI
PC4.GPIO_Label=LED_RED
PC4.Signal=GPIO_Output
PC5.GPIO_Label=LED_WHITE
PC5.Signal=GPIO_Output
PD0.GPIO_Label=RF1_CSN
PD0.Signal=GPIO_Output
PD1.GPIO_Label=RF1_CE
PD1.Signal=GPIO_Output
PD12.GPIO_Label=I2C_SCL_EXT
PD12.Signal=I2C4_SCL
PD13.GPIO_Label=I2C_SDA_EXT
PD13.Signal=I2C4_SDA
PD5.GPIO_Label=RF2_IRQ
PD5.Signal=GPXTI5
PD6.GPIO_Label=RF2_CSN
PD6.Signal=GPIO_Output
PD7.GPIO_Label=RF2_CE
PD7.Signal=GPIO_Output
PE11.GPIO_Label=CS_OF
PE11.Signal=GPIO_Output
PE12.GPIO_Label=OF_RST
PE12.Signal=GPIO_Output
PE13.GPIO_Label=OF_MOT
PE13.Signal=GPXTI13
PE14.GPIO_Label=CS_SD
PE14.Signal=GPIO_Output
PE15.GPIO_Label=IRQ_DRDY
PE15.Signal=GPIO_Input
PE2.GPIO_Label=SCK_F
PE2.Signal=SPI4_SCK
PE3.GPIO_Label=CS_F
PE3.Signal=GPIO_Output
PE5.GPIO_Label=MISO_F
PE5.Signal=SPI4_MISO
PE6.GPIO_Label=MOSI_F
PE6.Signal=SPI4_MOSI

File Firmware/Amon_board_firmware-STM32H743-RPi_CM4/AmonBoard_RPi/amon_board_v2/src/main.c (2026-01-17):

#include "main.h"
#include <stdio.h>

void app_run(void) {
    printf("Amon Lander starting...\n");
    
    // Initialize GNSS module
    gnss_init();
    
    // Get GNSS data
    GnssData gps_data;
    gnss_update(&gps_data);
    
    printf("Altitude: %.1fm, Speed: %.1fm/s, Satellites: %d\n",
           gps_data.altitude, gps_data.speed, gps_data.satellites);
    
    gnss_cleanup();
    printf("Amon Lander finished.\n");
}

int main() {
    app_run();
    return 0;
}

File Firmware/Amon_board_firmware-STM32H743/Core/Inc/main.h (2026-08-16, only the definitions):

#define SCK_F_Pin GPIO_PIN_2
#define SCK_F_GPIO_Port GPIOE
#define CS_F_Pin GPIO_PIN_3
#define CS_F_GPIO_Port GPIOE
#define MISO_F_Pin GPIO_PIN_5
#define MISO_F_GPIO_Port GPIOE
#define MOSI_F_Pin GPIO_PIN_6
#define MOSI_F_GPIO_Port GPIOE
#define ADC1_10_EDF_Pin GPIO_PIN_0
#define ADC1_10_EDF_GPIO_Port GPIOC
#define ADC1_11_MAIN_Pin GPIO_PIN_1
#define ADC1_11_MAIN_GPIO_Port GPIOC
#define SERVO_XP_Pin GPIO_PIN_0
#define SERVO_XP_GPIO_Port GPIOA
#define SERVO_XN_Pin GPIO_PIN_1
#define SERVO_XN_GPIO_Port GPIOA
#define SERVO_YP_Pin GPIO_PIN_2
#define SERVO_YP_GPIO_Port GPIOA
#define SERVO_YN_Pin GPIO_PIN_3
#define SERVO_YN_GPIO_Port GPIOA
#define ADC1_18_BUCK_5V_Pin GPIO_PIN_4
#define ADC1_18_BUCK_5V_GPIO_Port GPIOA
#define EN_BUCK_5V_Pin GPIO_PIN_5
#define EN_BUCK_5V_GPIO_Port GPIOA
#define ADC1_3_BUCK_7V2_Pin GPIO_PIN_6
#define ADC1_3_BUCK_7V2_GPIO_Port GPIOA
#define EN_BUCK_7V2_Pin GPIO_PIN_7
#define EN_BUCK_7V2_GPIO_Port GPIOA
#define LED_RED_Pin GPIO_PIN_4
#define LED_RED_GPIO_Port GPIOC
#define LED_WHITE_Pin GPIO_PIN_5
#define LED_WHITE_GPIO_Port GPIOC
#define AUX_PORT_Pin GPIO_PIN_0
#define AUX_PORT_GPIO_Port GPIOB
#define EDF_Pin GPIO_PIN_1
#define EDF_GPIO_Port GPIOB
#define CS_OF_Pin GPIO_PIN_11
#define CS_OF_GPIO_Port GPIOE
#define OF_RST_Pin GPIO_PIN_12
#define OF_RST_GPIO_Port GPIOE
#define OF_MOT_Pin GPIO_PIN_13
#define OF_MOT_GPIO_Port GPIOE
#define OF_MOT_EXTI_IRQn EXTI15_10_IRQn
#define CS_SD_Pin GPIO_PIN_14
#define CS_SD_GPIO_Port GPIOE
#define IRQ_DRDY_Pin GPIO_PIN_15
#define IRQ_DRDY_GPIO_Port GPIOE
#define I2C_SCL_S_Pin GPIO_PIN_10
#define I2C_SCL_S_GPIO_Port GPIOB
#define I2C_SDA_S_Pin GPIO_PIN_11
#define I2C_SDA_S_GPIO_Port GPIOB
#define UART5_RX_USB_Pin GPIO_PIN_12
#define UART5_RX_USB_GPIO_Port GPIOB
#define UART5_TX_USB_Pin GPIO_PIN_13
#define UART5_TX_USB_GPIO_Port GPIOB
#define UART1_TX_GPS_Pin GPIO_PIN_14
#define UART1_TX_GPS_GPIO_Port GPIOB
#define UART1_RX_GPS_Pin GPIO_PIN_15
#define UART1_RX_GPS_GPIO_Port GPIOB
#define I2C_SCL_EXT_Pin GPIO_PIN_12
#define I2C_SCL_EXT_GPIO_Port GPIOD
#define I2C_SDA_EXT_Pin GPIO_PIN_13
#define I2C_SDA_EXT_GPIO_Port GPIOD
#define RF1_IRQ_Pin GPIO_PIN_12
#define RF1_IRQ_GPIO_Port GPIOA
#define RF1_IRQ_EXTI_IRQn EXTI15_10_IRQn
#define SPI3_SCK_RF_Pin GPIO_PIN_10
#define SPI3_SCK_RF_GPIO_Port GPIOC
#define SPI3_MISO_RF_Pin GPIO_PIN_11
#define SPI3_MISO_RF_GPIO_Port GPIOC
#define SPI3_MOSI_RF_Pin GPIO_PIN_12
#define SPI3_MOSI_RF_GPIO_Port GPIOC
#define RF1_CSN_Pin GPIO_PIN_0
#define RF1_CSN_GPIO_Port GPIOD
#define RF1_CE_Pin GPIO_PIN_1
#define RF1_CE_GPIO_Port GPIOD
#define RF2_IRQ_Pin GPIO_PIN_5
#define RF2_IRQ_GPIO_Port GPIOD
#define RF2_IRQ_EXTI_IRQn EXTI9_5_IRQn
#define RF2_CSN_Pin GPIO_PIN_6
#define RF2_CSN_GPIO_Port GPIOD
#define RF2_CE_Pin GPIO_PIN_7
#define RF2_CE_GPIO_Port GPIOD
#define RGB_R_Pin GPIO_PIN_6
#define RGB_R_GPIO_Port GPIOB
#define RGB_G_Pin GPIO_PIN_7
#define RGB_G_GPIO_Port GPIOB
#define RGB_B_Pin GPIO_PIN_8
#define RGB_B_GPIO_Port GPIOB
#define LED_BRD_Pin GPIO_PIN_9
#define LED_BRD_GPIO_Port GPIOB

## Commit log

2025-08-30 First commit
    separated Amon lander project, PCB+SW only
    [Amon_board-B_Cu.gbl, Amon_board-B_Mask.gbs, Amon_board-B_Paste.gbp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]
2025-08-30 Update
    readme
    [Amon_board-B_Cu.gbl, Amon_board-B_Mask.gbs, Amon_board-B_Paste.gbp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]
2026-01-17 Update
    A lot of code changes, radio driver implementation, basic decoding implementetion, state machine changed
    [Amon_board.kicad_pcb]
2026-02-02 Update
    corected complementary filter, optimized telemetry send from 5 to 50Hz, start of Kalman filter development
2026-03-06 Update
    Implementation of logging - LittleFS, 50Hz, external flash
2026-03-07 Update
    Implementation of serial connection to drone, state change over radio (arm, flight start, flight stop...)
2026-03-08 Update
    functional logging (arm, flying, landed) and log dump over uart on gps port
2026-03-11 Update
    GNSS implemented, logging (flash) and radio works on the same bus - switching between SPI bus speed
2026-03-18 Update
    new flight controller development started (v3)
    [Amon_board-B_Cu.gbl, Amon_board-B_Mask.gbs, Amon_board-B_Paste.gbp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]
2026-03-30 Update
    compas driver - untested
    [Amon_board.kicad_pcb, microcontroller.kicad_sch, power.kicad_sch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]
2026-04-05 Update
    added first flight path buffer
    [Amon_board.kicad_sch, microcontroller.kicad_sch, rf.kicad_sch]
2026-05-14 Update: development of new PCB_v3
    [Amon_board.kicad_pcb, outputs.kicad_sch]
2026-05-16 Update: finished routing of PCB_v3
    [Amon_board.kicad_pcb, Amon_board.kicad_sch, microcontroller.kicad_sch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]
2026-05-17 Update: finished PCB v3, gerbers, ordered board, readme update
    [Amon_board-B_Cu.gbl, Amon_board-B_Mask.gbs, Amon_board-B_Paste.gbp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]
2026-05-21 Update: code ported from stm32f4 to stm32h7 - untested
2026-05-27 Update: PMW3901 gyro compensation and distance tracking, autopilot start
2026-05-31 Update: PCB bringup in progress, some modifications done, fw in development
    [power.kicad_sch]
2026-06-06 Update: full FW port to PCB_v3 with all SPI problems solved, corrected timers, untested on craft
    [Ozone_Registers_1_260605.csv, power.kicad_sch]
2026-06-08 Update: working and correctly mapped compas to drone body
    [Amon_board_firmware_v3.ioc, drone_data.h, main.c]
2026-07-03 Update: clean rearm, corrected timers, corrected logging with raw data in flash
    [Amon_board_firmware_v3.ioc, NMPC.h, drone_data.c]
2026-07-04 Bugfix: crc in UART TX
    [data_transcode.c, drone_data.h, main.c]
2026-07-07 Bugfix: TOF units, log TOF
    [NMPC.h, PWM.h, drone_data.h]
2026-07-23 Update: radio channel setup, nmpc, logging, code cleanup
    [Amon_board.kicad_pcb, Amon_board.step]
2026-08-16 Update: NMPC development, 1st order model, single file selection
    [Amon_board.kicad_pcb, Amon_board.kicad_sch, sensors.kicad_sch]

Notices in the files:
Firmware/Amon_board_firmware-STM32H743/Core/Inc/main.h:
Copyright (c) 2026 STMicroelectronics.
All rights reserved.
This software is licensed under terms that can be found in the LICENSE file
